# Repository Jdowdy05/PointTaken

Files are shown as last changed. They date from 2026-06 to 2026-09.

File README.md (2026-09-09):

# Point Taken — An Optical Tactile Fingertip

A compact optical tactile fingertip built around the **ams OSRAM TMF8829**. A soft silicone surface deforms under contact; the sensor observes the changing distance to its reflective inner layer. Force and contact information must be obtained through calibration.

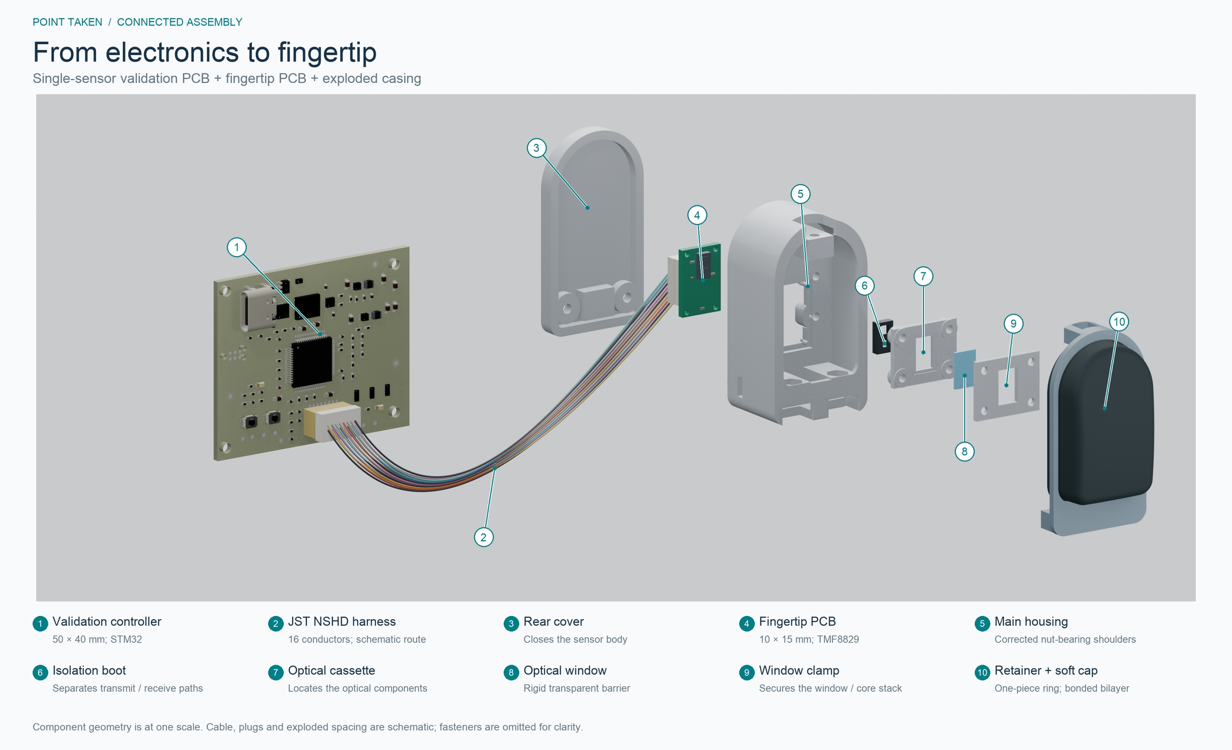
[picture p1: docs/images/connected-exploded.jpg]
Single-sensor validation PCB connected to the fingertip PCB, with the sensor housing and optical components shown in an exploded assembly


*Connected electronics and exploded sensor assembly. Cable routing and exploded spacing are schematic.*

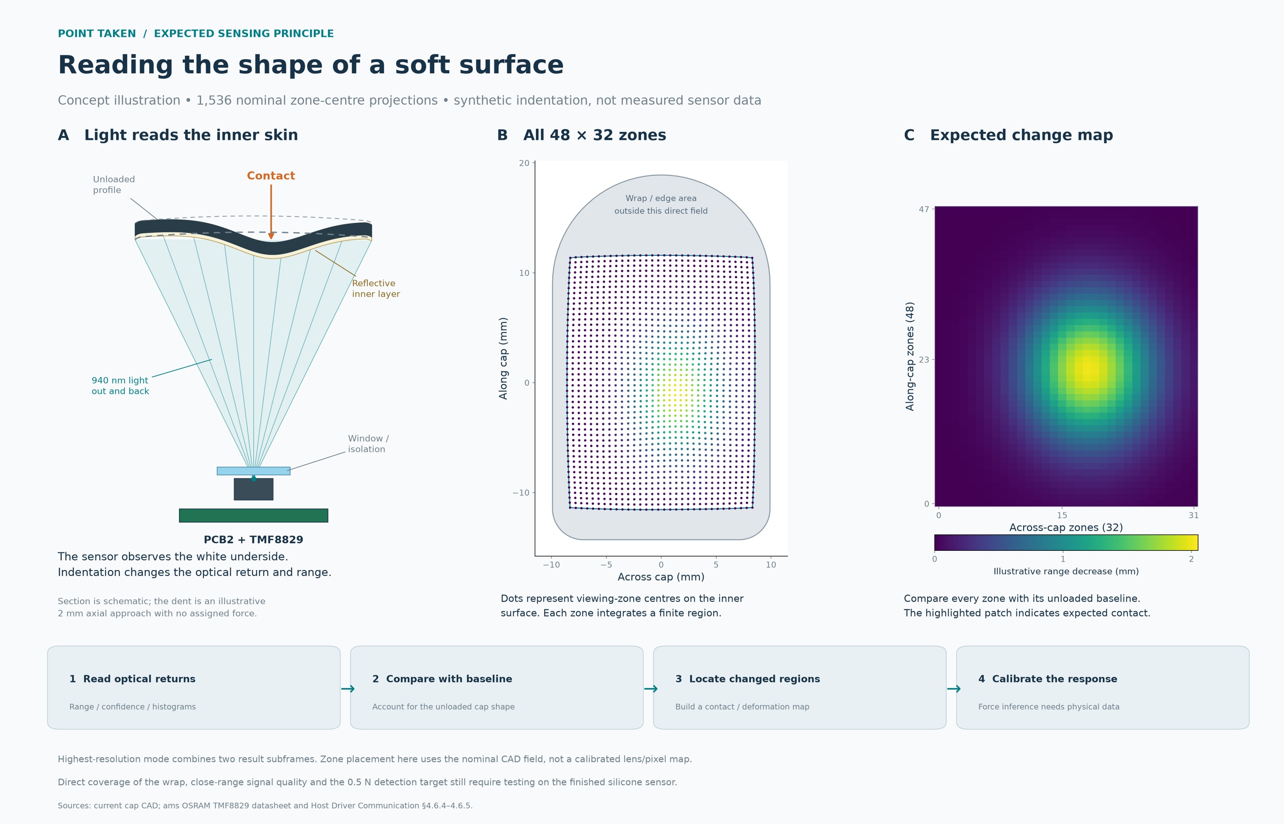
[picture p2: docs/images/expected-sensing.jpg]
Expected optical sensing: representative viewing zones on the reflective inner skin and an illustrative deformation map


*Expected sensing principle. The zone projection and deformation example are illustrative, not calibrated measurements.*

<p align="center">
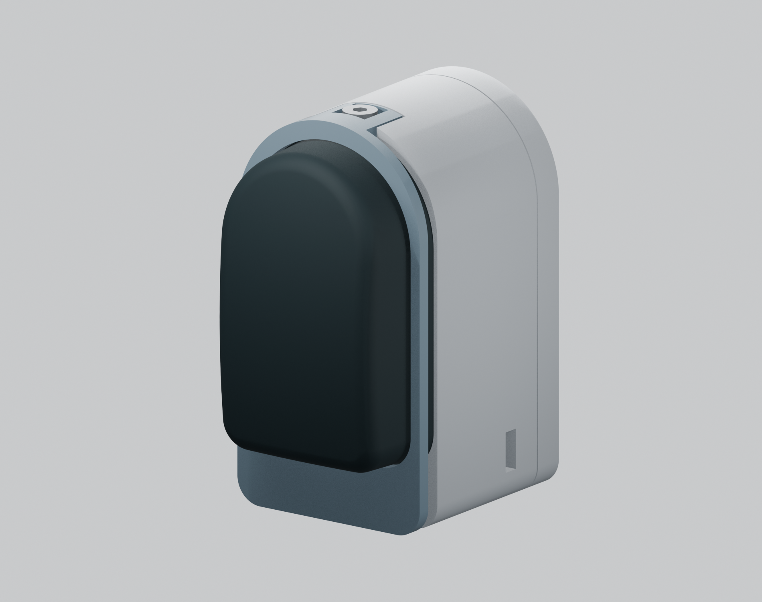
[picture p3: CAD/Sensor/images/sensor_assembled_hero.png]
Assembled Point Taken tactile fingertip
  
</p>

## Repository layout

| Folder | Contents |
| --- | --- |
| [PCBs/](PCBs/) | Native KiCad projects for the five-sensor controller, single-sensor validation rig and fingertip board, plus shared symbols, footprints and 3D reference models. |
| [CAD/Sensor/](CAD/Sensor/) | Corrected sensor housing, one-piece cap retainer, optical parts, compliant-surface geometry, assembled STEP and printable rigid-part STLs. |
| [docs/](docs/) | Material notes, assembly instructions, harness pinout and manufacturer references. |

## Design specifications

| Property | Current design |
| --- | --- |
| Sensing IC | TMF8829 direct time-of-flight sensor; up to **48 ×32 zones** and **940 nm** near-infrared illumination. |
| Sensor enclosure | **24.2 mm wide ×44.5 mm high ×33.8 mm deep**, including the rear locating posts. |
| Fingertip PCB | **10 ×15 mm**, four copper layers, one TMF8829 and four 1.20 mm mounting holes. |
| Main controller | **50 ×50 mm**, six layers, STM32H573ZIT6 and up to five sensor ports; placement complete, **unrouted**. |
| Validation controller | **50 ×40 mm**, six layers, STM32H562RIT6 and one sensor port; routed prototype. |
| Sensor connection | 16-conductor JST NSHD wire harness; SPI primary, optional I3C/I2C lines. |
| Supply architecture | Protected 5 V USB-C controller input; 3.3 V and 1.8 V sensor rails, with an explicit I/O supply. |
| Compliant skin | Nominal **0.90 mm black outer layer +0.30 mm white inner layer**, 1.20 mm total. |
| Target-motion allowance | **6 mm** optical travel allocation; not a measured deformation or force rating. |
| Front retention | **One-piece ring**, three M2 ×6 screws, mechanically captured silicone flange/bead. |
| Rear retention | Two **M2 ×8 screws** for the standalone sensor; side-loaded M2 nuts bear on 4 mm housing shoulders. |

IC capabilities are from the [TMF8829 manufacturer information](https://ams-osram.com/products/sensor-solutions/direct-time-of-flight-sensors-dtof/ams-tmf8829-48x32-multi-zone-time-of-flight-sensor). They do not establish this prototype's effective tactile resolution, frame rate or calibrated force accuracy.

## What the deformable surface should be made from

The current prototype material candidate is **Smooth-On Ecoflex 00-30 platinum-cure silicone**, cast as a bonded two-layer membrane:

- **Outside:** approximately 0.90 mm of black-pigmented silicone to provide the contact surface and block ambient light.
- **Inside:** approximately 0.30 mm of white, titanium-dioxide-filled silicone to provide a diffuse reflective target at 940 nm.

The flexible cap is a cast silicone part. The files in `CAD/Sensor/print/` are the rigid parts intended for 3D printing; compliant-surface meshes describe the casting geometry.

[Ecoflex 00-30 manufacturer instructions](https://www.smooth-on.com/products/ecoflex-00-30/) specify a 1A:1B base mix. Follow the current technical bulletin for preparation and curing. **Pigment/TiO₂ loading and the two-layer bonding process are not yet qualified** for this cap. Black appearance alone does not prove infrared opacity, and white appearance does not establish adequate sensor return. See [Materials](docs/Materials.md) before casting.

## Sensitivity and load targets

These are **design targets, not measured specifications**:

- Detect **0.5 N normal contact**, at least five standard deviations above unloaded repeatability noise over the central 80% of the contact surface.
- Stretch goal: **0.10–0.25 N** detection.
- Produce at least **0.25 mm local target displacement at 0.5–1.0 N** centre load.
- Original mechanical goals: **30 N normal load and 75 N brief overload**. These have not been established for the current cap/housing.

The current state is **a CAD-checked hardware prototype awaiting physical qualification**. CAD clearance checks do not prove sensitivity, tear resistance, layer adhesion, fatigue, creep or overload survival. The single-sensor validation rig and fingertip PCB have routing; the five-sensor controller remains on manufacturing hold. No fabrication or assembly approval is implied by this publication.

## Open and build

1. Open a `.kicad_pro` from [PCBs/](PCBs/) using **KiCad 10** with its standard libraries installed. Project-local library paths are portable.
2. Open [sensor_assembly.step](CAD/Sensor/sensor_assembly.step) in FreeCAD or another STEP-compatible CAD tool. All CAD dimensions are millimetres.
3. Use the **five rigid-part STLs** in [CAD/Sensor/print/](CAD/Sensor/print/), and read the [assembly instructions](docs/Assembly.md). The corrected main housing and one-piece retainer are included.
4. Verify printed nut fits, layer construction and the actual electronics before powered testing. Calibrate the finished silicone article before interpreting deformation as force.

The STEP files provide editable solid geometry; native parametric feature history is not included in this publication. Manufacturer reference documents and component models are identified in [References](docs/References.md).

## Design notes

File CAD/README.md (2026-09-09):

# Sensor CAD

[Sensor/](Sensor/) contains the current standalone tactile sensor, including the corrected rear nut shoulders and one-piece front ring.

Use STEP for solid CAD and the selected STL files for rigid-part printing. The assembly includes reference electronics, the two soft layers and nominal hardware. Component/hardware envelopes are not standalone rigid print jobs.

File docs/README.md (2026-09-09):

# Documentation

- [Assembly](Assembly.md): five rigid parts, fasteners, side-loaded rear nuts and one-piece cap ring.
- [Materials](Materials.md): Ecoflex bilayer candidate, optical additives and qualification limits.
- [Harness](Harness.md): 16-wire JST NSHD connector pinout.
- [References](References.md): manufacturer documentation and reference-model provenance.

The root [README](../README.md) lists the hardware dimensions and design targets.

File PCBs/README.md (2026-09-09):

# PCB projects

Open the `.kicad_pro` file in the appropriate folder with KiCad 10 and its standard symbol, footprint and 3D model libraries.

| Project | Nominal board size | Layers | Purpose and state |
| --- | --- | ---: | --- |
| [PCB1_Controller](PCB1_Controller/) | 50 ×50 mm | 6 | Five-sensor STM32H573 controller. Placement present; zero tracks/vias. Unrouted and on manufacturing hold. |
| [PCB1_Single_Sensor_Validation_Rig](PCB1_Single_Sensor_Validation_Rig/) | 50 ×40 mm | 6 | STM32H562 single-sensor bring-up controller. Routed prototype. |
| [PCB2_Fingertip_Sensor](PCB2_Fingertip_Sensor/) | 10 ×15 mm | 4 | TMF8829 fingertip module. Routed prototype. |

`JustTheTip_Connectors.pretty/` and `3dmodels/` are shared by the three projects. Keep the folder relationships intact. Custom symbols and other custom footprints are stored beside their owning projects. Library tables use `${KIPRJMOD}`, `${KICAD10_SYMBOL_DIR}` and `${KICAD10_FOOTPRINT_DIR}`; stock component models use `${KICAD10_3DMODEL_DIR}`.

Schematic and board files retain the electrical design contents. Publication changes library paths and organization, not electrical routing. Four nonexistent PCB1 stock-model references now point to the included exact-part envelope proxies for TCPP01-M12, ESDA25P35-1U1M, TPS259531 and CSD17577Q5A. Native board loading and schematic/board SVG exports were checked; `manifest.json` records file hashes and board statistics. These publication checks are not a fresh ERC/DRC, EMC or manufacturing review.

Each project has `previews/top.svg`, `previews/bottom.svg` and schematic pages in `previews/schematics/`. Bottom previews use the board's unmirrored coordinate convention. Copper plots are for inspection, not fabrication files. Generate fabrication outputs from the selected source revision after reviewing its rules, stackup, DRC/ERC and manufacturing requirements.

The hierarchical filename `Sensor_FFC_Ports.kicad_sch` in PCB1 is historical: its actual connector interface is JST NSHD discrete wire. See the [16-wire interface](../docs/Harness.md).

The custom 3D models named `*_proxy.step` are envelope approximations for packaging; manufacturer drawings govern exact component and mating dimensions.

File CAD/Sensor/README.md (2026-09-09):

# Standalone fingertip sensor

Envelope: **24.2 ×44.5 ×33.8 mm** (width ×height ×depth, including rear locating posts).

| Path | Use |
| --- | --- |
| `sensor_assembly.step` | Complete 54-solid sensor assembly, including PCB and hardware references. |
| `parts/` | Five rigid-part STEP files. |
| `print/` | Matching STL files for the main housing, back housing, one-piece retainer, optical cassette and window clamp. |
| `compliant_surface/` | Black outer cap and white inner target STEP/STL geometry for silicone casting. |
| `reference/` | PCB, optical boot and window reference solids/meshes. |
| `images/` | Actual CAD renders, including six assembled views and an exploded assembly. |
| `manifest.json` | Dimensions, file hashes, export checks and standalone rear-fastener contact checks. |

The cap and retainer remove together after the three M2 ×6 front screws are removed. Separating the silicone from the one-piece ring requires flexing the flange and must be tried on a sacrificial cap. The corrected rear nuts load from the sides and bear on main-housing shoulders; the standalone rear screws are M2 ×8.

Coordinates are X across the sensor, Y toward the arched tip and Z toward the contact surface. All dimensions are millimetres. Orient parts deliberately in the slicer. Candidate rigid material is FDM PETG; printer tolerances, nut fit and allowable tightening torque need physical verification.

These are editable STEP solids and STL exports. The CAD construction feature history is not included. [Assembly](../../docs/Assembly.md) and [material guidance](../../docs/Materials.md) apply to this revision.

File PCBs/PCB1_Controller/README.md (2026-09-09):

# PCB1 Controller

Open [PCB1_Controller.kicad_pro](PCB1_Controller.kicad_pro) in KiCad 10.

Five-sensor controller; placement only, zero tracks/vias. Manufacturing hold.

- [Top copper/silkscreen preview](previews/top.svg)
- [Bottom copper/silkscreen preview](previews/bottom.svg)
- [Schematic pages](previews/schematics/)

Keep the shared connector and 3D-model folders alongside the board project. See the [PCB index](../README.md) for library setup and status.

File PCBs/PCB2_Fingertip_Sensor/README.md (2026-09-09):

# PCB2 Fingertip Sensor

Open [PCB2_Fingertip_Sensor.kicad_pro](PCB2_Fingertip_Sensor.kicad_pro) in KiCad 10.

Routed prototype. Native source is included; physical bring-up and manufacturing review remain necessary.

- [Top copper/silkscreen preview](previews/top.svg)
- [Bottom copper/silkscreen preview](previews/bottom.svg)
- [Schematic pages](previews/schematics/)

Keep the shared connector and 3D-model folders alongside the board project. See the [PCB index](../README.md) for library setup and status.

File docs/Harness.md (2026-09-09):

# Sensor harness

The connector is a 16-circuit, 1.0 mm pitch JST NSHD wire harness: BM16B-NSHDZS-TFT board headers, NSHDR-16V-Z housings and SNSHD-003T-P0.2 contacts.

| Pin | Signal | Notes |
| --- | --- | --- |
| 1 | GND | Ground return. |
| 2 | 3V3_TOF | Sensor 3.3 V rail. |
| 3 | TOF_VIO | TMF8829 I/O rail; strapped to 3.3 V on PCB1 by default. |
| 4 | GND | Power return. |
| 5 | 1V8_TOF | Sensor VDDD rail. |
| 6 | GND | Power return. |
| 7 | SPI_SCLKx | Per-port SCLK preferred. |
| 8 | SPI_MOSIx | Per-port MOSI preferred. |
| 9 | SPI_MISOx | Per-port MISO preferred. |
| 10 | SPI_CSn | Per-port chip select. |
| 11 | I3C_SCLx / AUX1 | Optional bring-up/debug I3C/I2C; pull up to TOF_VIO. |
| 12 | I3C_SDAx / AUX2 | Optional bring-up/debug I3C/I2C; pull up to TOF_VIO. |
| 13 | ENx | Per-port sensor enable. |
| 14 | INTx | Per-port interrupt. |
| 15 | DET_IDx | Presence/revision detection. |
| 16 | GND | Fourth ground return at the cable edge. |

Pin numbers and signal roles match the native PCB2 connector. Net names vary by controller; pin 3 is the explicit I/O supply and pin 16 is ground. Define housing orientation and pin-1-to-pin-1 continuity in the physical harness drawing before assembly. The older FFC/FPC interface is retired.

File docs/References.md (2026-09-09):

# References and component geometry

- [ams OSRAM TMF8829 product and datasheets](https://ams-osram.com/products/sensor-solutions/direct-time-of-flight-sensors-dtof/ams-tmf8829-48x32-multi-zone-time-of-flight-sensor): sensor capabilities, electrical interface and optical guidance. Existing reference PDFs and optical models are retained under `references/`.
- [Smooth-On Ecoflex 00-30](https://www.smooth-on.com/products/ecoflex-00-30/): current prototype silicone candidate and preparation/cure instructions.
- [Smooth-On Dragon Skin 10 NV technical bulletin](https://www.smooth-on.com/tb/files/DRAGON_SKIN_10_NV_TB.pdf): earlier outer-layer material candidate.
- [Stretchable silicone reflective coating study](https://doi.org/10.1039/D2SM00869F): supporting material research; its formulation does not qualify the current sensor.
- [JST NSHD series](https://www.jst-mfg.com/product/pdf/eng/eNSHD.pdf): board header, cable housing, contacts and recommended footprint.
- [KiCad libraries](https://www.kicad.org/libraries/): standard symbols, footprints and 3D models used by the PCB projects.

Files named `*_proxy.step` are project component-envelope approximations. The PCB/CAD assembly also includes optical reference geometry; use manufacturer drawings for exact dimensions, optical tolerances and mating requirements. No model color establishes a material's infrared properties.

Manufacturer documents and reference geometry retain their original ownership and terms. KiCad-derived library content remains subject to its upstream terms. This repository does not declare a blanket license over third-party reference material, and no new project-wide license is assigned by this update.

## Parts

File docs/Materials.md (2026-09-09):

# Compliant surface material

## Current prototype candidate

Use **Ecoflex 00-30 platinum-cure silicone** as the starting base material for the current cap study. It is a candidate formulation, not a demonstrated route to the required force sensitivity. The [manufacturer product page and technical bulletin](https://www.smooth-on.com/products/ecoflex-00-30/) govern its 1A:1B mixing and curing instructions.

| Layer | Nominal normal thickness | Purpose |
| --- | ---: | --- |
| Black outer silicone | 0.90 mm | Contact skin and ambient-light suppression. |
| White TiO₂-filled inner silicone | 0.30 mm | Flexible diffuse reflective target facing the 940 nm sensor. |
| Total skin | 1.20 mm | Bonded bilayer; the inner target deforms with the outside. |

Use silicone-compatible black pigment and a dispersed white titanium-dioxide additive suitable for the selected silicone process. There is no approved additive mass fraction for this final geometry. Additives can change cure, stiffness and optical response, so do not infer performance from color or unfilled-silicone hardness alone.

The intended process is a two-stage cast with reliable interlayer bonding. Preserve the designed flange and bead: the ring mechanically captures those features. The geometry files do not constitute a qualified mold, gate/vent layout or casting process.

## Earlier material study

The original material study proposed Dragon Skin 10 NV outside and Ecoflex 00-10 with micrometric rutile TiO₂ inside. A 1.0 vol% TiO₂ coating was a research starting point, not a validated recipe for Ecoflex 00-30 or this cap. The current cap source identifies Ecoflex 00-30 as a later candidate; physical testing has not resolved the formulation choice. These alternatives should not be treated as interchangeable qualified materials.

## Qualification required

- Cure compatibility, consistent wall thickness and two-layer adhesion.
- Infrared opacity of the black skin at its actual thickness; original target was optical density ≥3 at 940 nm (≤0.1% direct transmission).
- Adequate diffuse return from the inner target without saturation or large baseline drift; original target was 70–90% diffuse/hemispherical return at 940 nm.
- Required 0.5 N contact detection and low-force target displacement after calibration of the actual article.
- Flange insertion/removal without tearing, skin abrasion, creep, fatigue and overload behavior.

The one-piece ring requires the silicone flange to flex during cap replacement. That service operation is not a proven strain or life result.

The compliant-surface STLs are casting references. FDM printing a TPU version changes the mechanics and would require a separate sensitivity evaluation. FDM-printed tooling, if developed, would need surface finishing, dimensional checks and a silicone cure-compatibility trial.

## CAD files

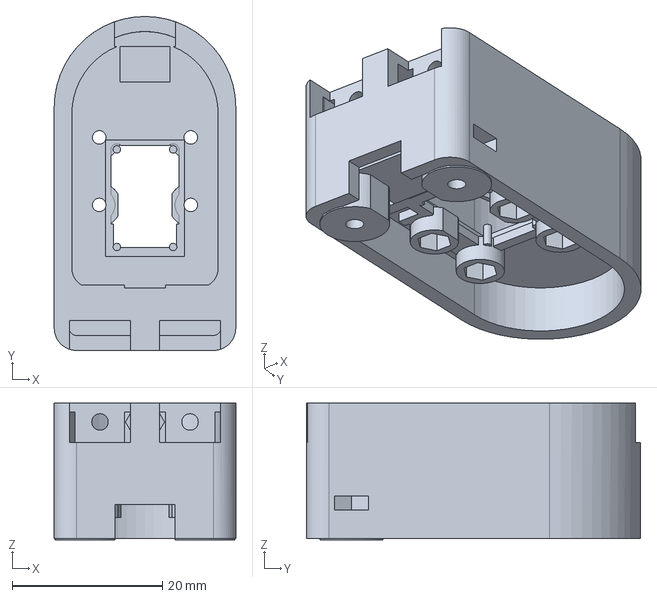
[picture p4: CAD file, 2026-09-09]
CAD/Sensor/parts/main_housing.step
24.2 x 44.5 x 18.2 mm

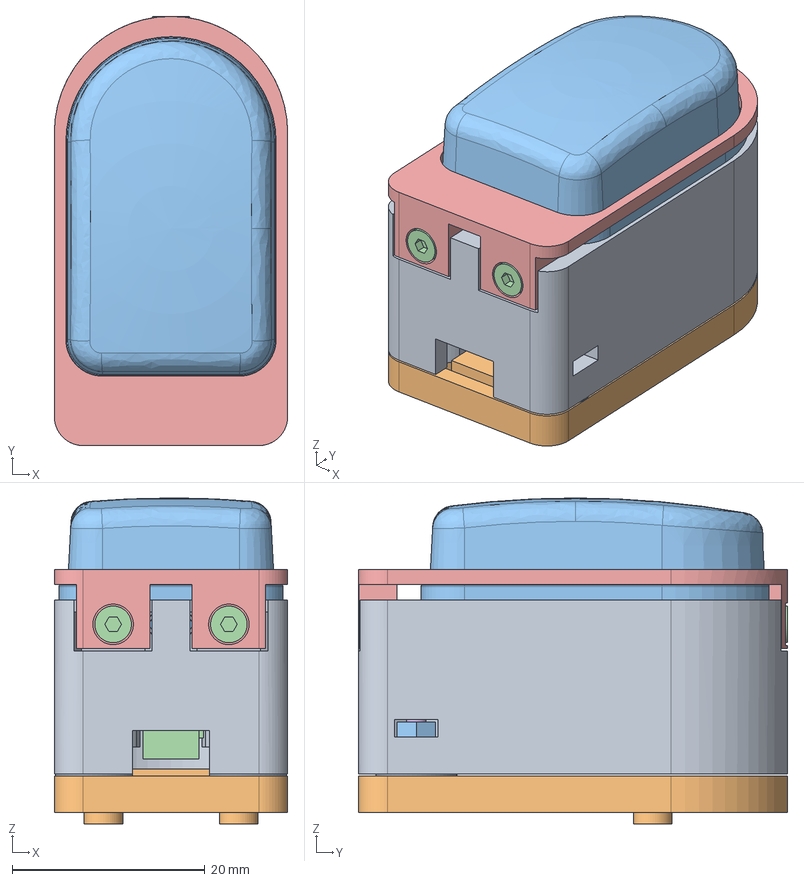
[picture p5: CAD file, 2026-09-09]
CAD/Sensor/sensor_assembly.step
24.2 x 44.5 x 33.8 mm

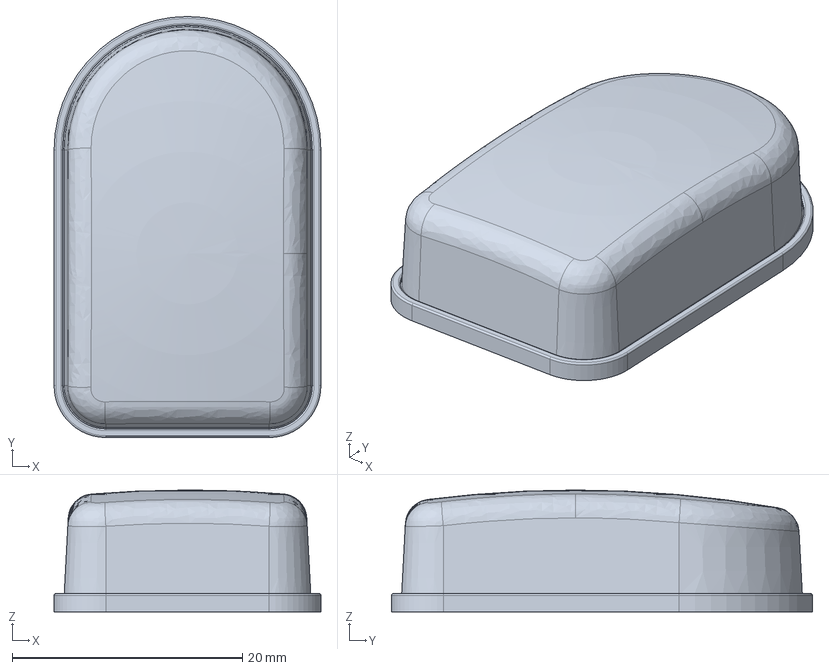
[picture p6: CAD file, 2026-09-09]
CAD/Sensor/compliant_surface/black_wrap_cap.step
23.2 x 36.6 x 10.6 mm

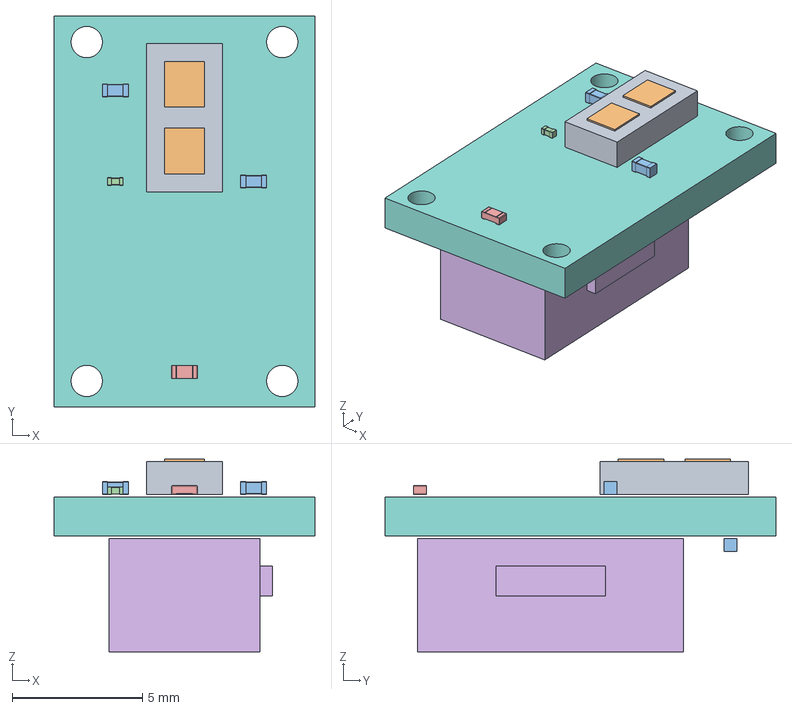
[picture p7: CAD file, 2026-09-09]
CAD/Sensor/reference/PCB2_reference.step
10.0 x 15.0 x 7.39 mm

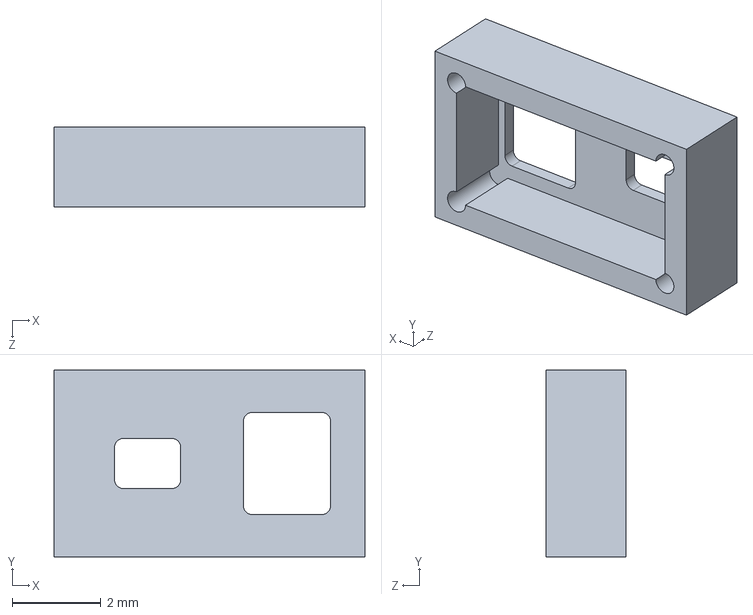
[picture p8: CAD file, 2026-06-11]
docs/references/TMF8829_Optical_Design_Guide/TMF8829_Rubber_Boot_0mm3.STEP
7.00 x 4.20 x 1.80 mm

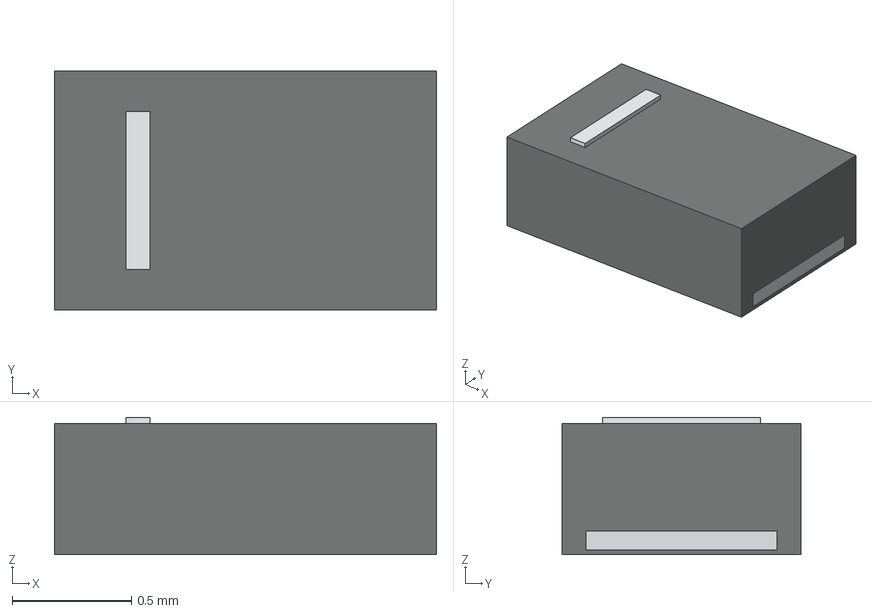
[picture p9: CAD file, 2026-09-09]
PCBs/3dmodels/ST_ESDA25P35_1U1M_QFN2_1p6x1p0_proxy.step
1.60 x 1.00 x 0.575 mm
molded_body
terminal_1
terminal_2
polarity_bar

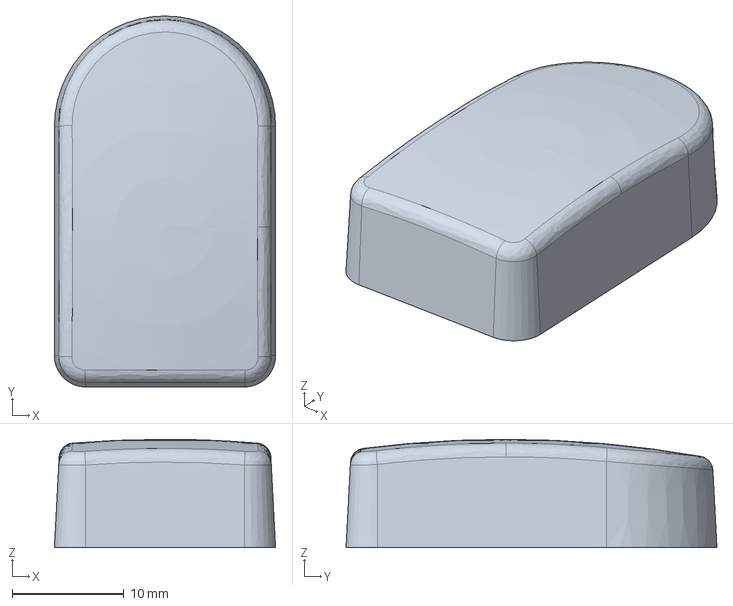
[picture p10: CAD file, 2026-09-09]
CAD/Sensor/compliant_surface/white_inner_target.step
19.8 x 33.2 x 9.70 mm

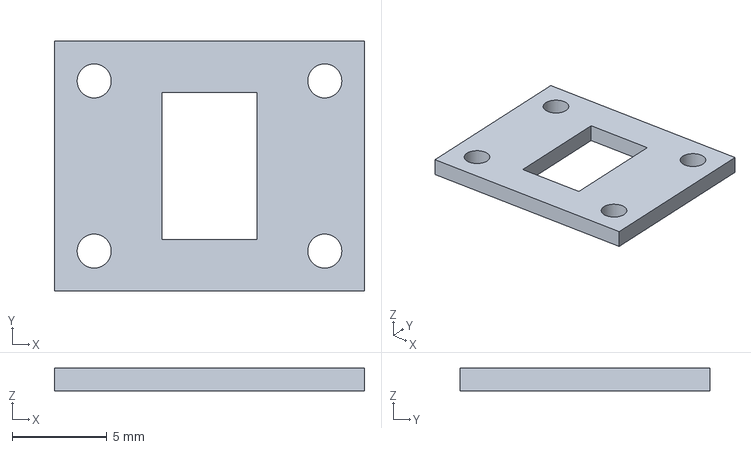
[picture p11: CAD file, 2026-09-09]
CAD/Sensor/parts/window_clamp.step
16.4 x 13.2 x 1.20 mm

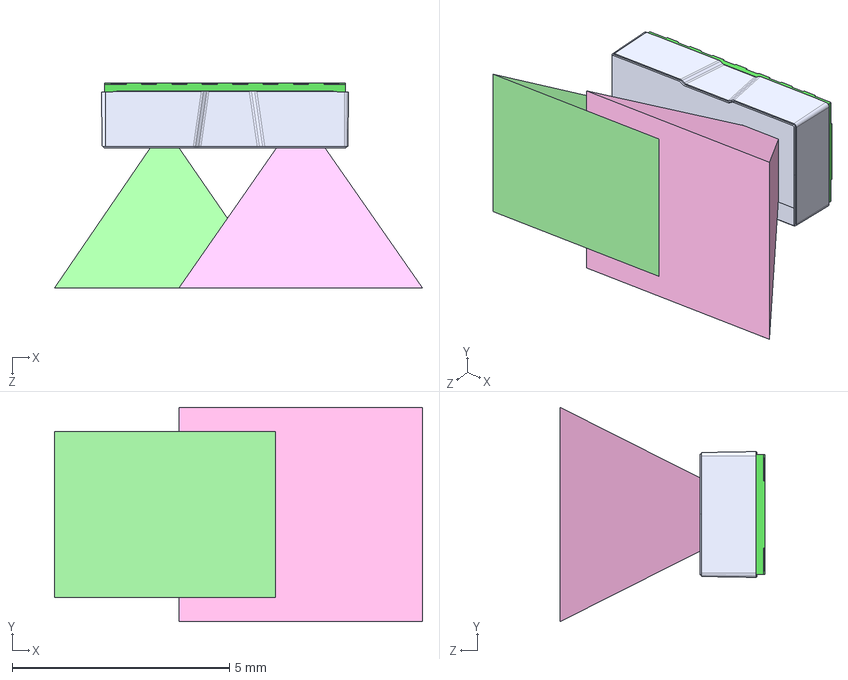
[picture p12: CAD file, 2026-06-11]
docs/references/TMF8829_Optical_Design_Guide/TMF8829_with_FOI_FOV.STEP
8.48 x 4.94 x 4.72 mm
Substrate_
Receiver_
CUT LID_
Lens1_withFOI
Lens2_
Emitter_WithConeFOI_ x 2
Lens2_with2FOI_combined_
LID_

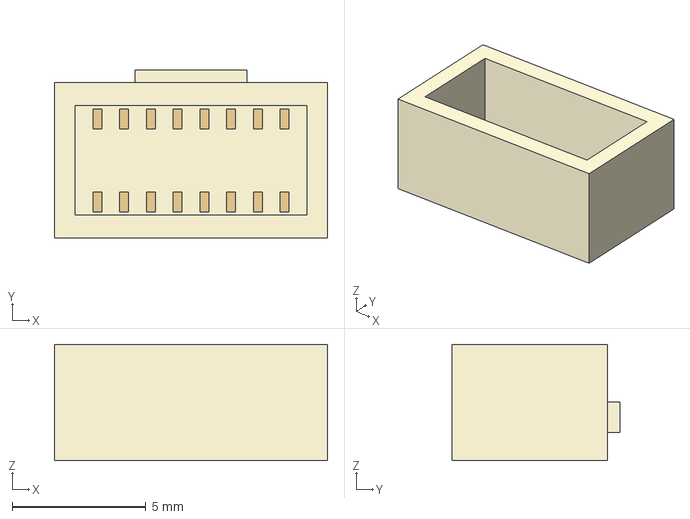
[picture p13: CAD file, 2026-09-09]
PCBs/3dmodels/JST_BM16B_NSHDZS_TFT_envelope_proxy.step
10.2 x 6.28 x 4.35 mm
ivory_shell
contacts

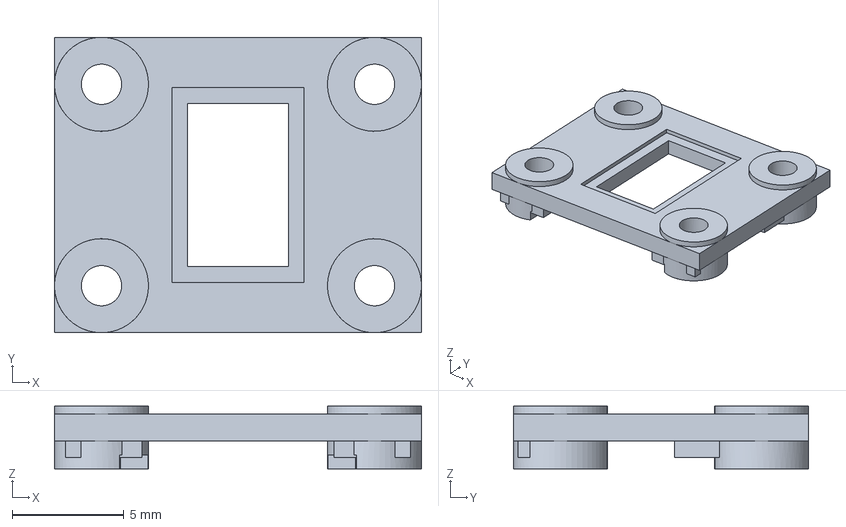
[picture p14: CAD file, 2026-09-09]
CAD/Sensor/parts/P3_optical_cassette.step
16.4 x 13.2 x 2.80 mm

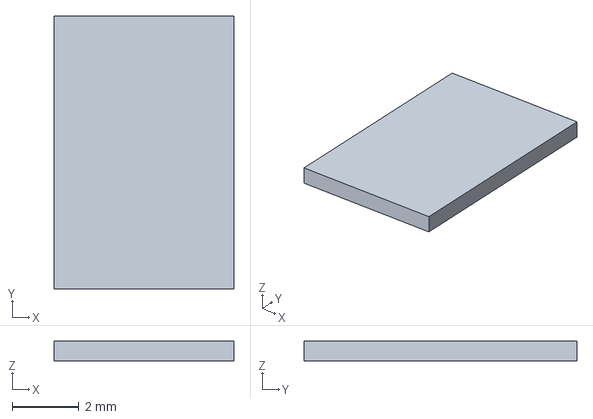
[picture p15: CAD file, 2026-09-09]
CAD/Sensor/reference/window_reference.step
5.40 x 8.20 x 0.6 mm

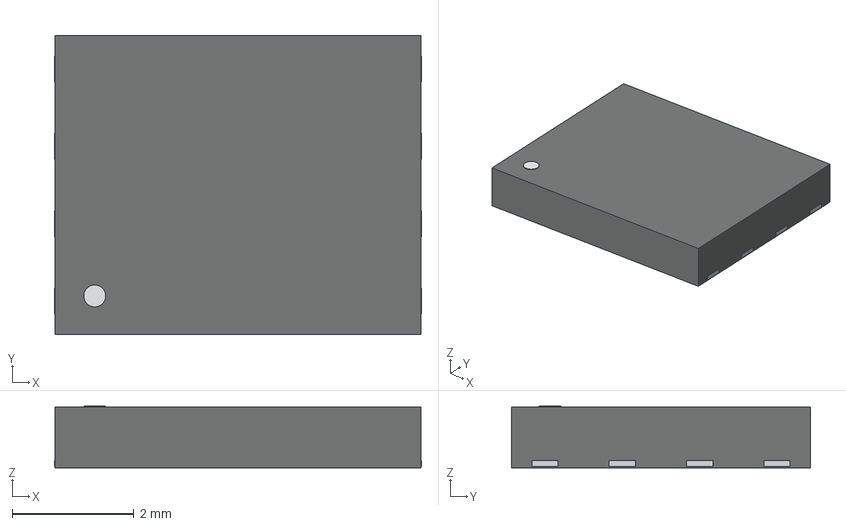
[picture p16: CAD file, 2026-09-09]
PCBs/3dmodels/TI_CSD17577Q5A_DQJ_6p0x4p9_proxy.step
6.02 x 4.90 x 1.01 mm
molded_body
terminal_flanks
pin_1_marker

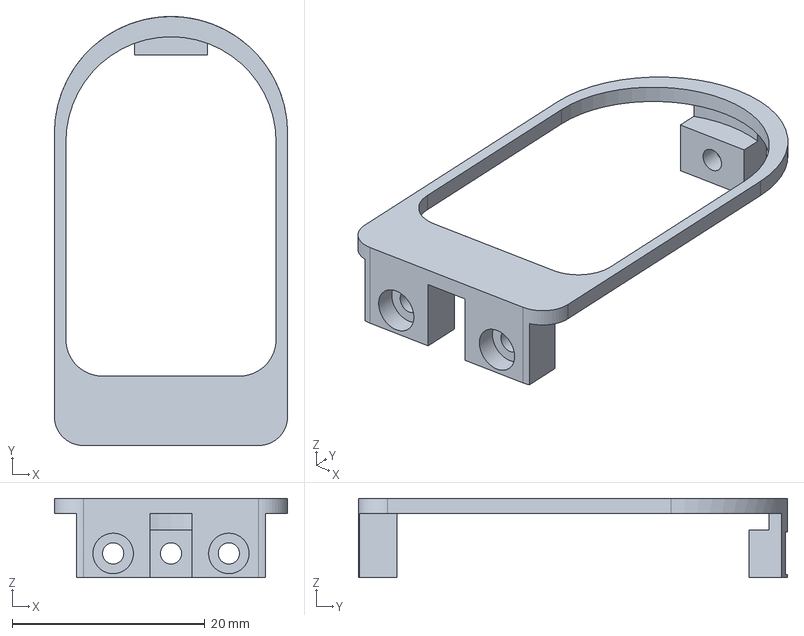
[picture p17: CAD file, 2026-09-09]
CAD/Sensor/parts/cap_retainer_one_piece.step
24.2 x 44.5 x 8.20 mm

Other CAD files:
CAD/Sensor/reference/boot_reference.step
PCBs/3dmodels/ST_TCPP01_M12_QFN12_3p0x3p0_proxy.step
CAD/Sensor/parts/back_housing.step
PCBs/3dmodels/TDK_TFM201610ALM_R47MTAA_2p0x1p6_proxy.step
CAD/Sensor/compliant_surface/black_wrap_cap.stl
CAD/Sensor/compliant_surface/white_inner_target.stl
CAD/Sensor/print/P3_optical_cassette.stl
CAD/Sensor/print/back_housing.stl
CAD/Sensor/print/cap_retainer_one_piece.stl
CAD/Sensor/print/main_housing.stl
CAD/Sensor/print/window_clamp.stl
CAD/Sensor/reference/PCB2_reference.stl
CAD/Sensor/reference/boot_reference.stl
CAD/Sensor/reference/window_reference.stl
PCBs/3dmodels/TI_DMQ0006A_VSON_HR_6_1p5x1p5_proxy.step
PCBs/3dmodels/TI_TPS259531_DSG0008A_2p0x2p0_proxy.step
PCBs/3dmodels/TMF8829_package_envelope_proxy.step

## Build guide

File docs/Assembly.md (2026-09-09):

# Sensor assembly

## Rigid parts and hardware

Print one each of the five parts in `CAD/Sensor/print/`: main housing, back housing, one-piece cap retainer, optical cassette and window clamp. The silicone cap/inner target, PCB, optical boot, window and metal fasteners are not rigid print jobs.

| Fastener | Quantity | Purpose |
| --- | ---: | --- |
| M1.6 ×8 socket-head screw | 4 | Optical core retention |
| M1.6 hex nut | 4 | Optical core retention |
| M2 ×6 socket-head screw | 3 | Front cap-retainer ring |
| M2 hex nut | 3 | Front retainer seats |
| M2 ×8 socket-head screw | 2 | Standalone back housing |
| M2 hex nut | 2 | Corrected side-loading rear seats |

Screw lengths are measured under the head. The modeled M2 nuts are 4.0 mm across flats and 1.6 mm thick. Check the actual hardware and printed pockets before assembly; there is no qualified tightening torque.

## Sequence

1. Inspect and finish the print surfaces and holes. Check each nut pocket and screw bore off the assembly. Ensure the rear nuts seat and resist spinning.
2. Assemble the PCB, cassette, optical boot and window/clamp with their four M1.6 fasteners. Keep the optical window clean, the transmit/receive isolation intact and the harness clear of hardware.
3. Fit the front retainer nuts into the housing before closing the front. Gently flex the cast cap's flange into the one-piece ring off the housing, checking the skins and flange for damage. This operation needs a physical trial on a sacrificial cap.
4. Seat the cap/ring cartridge on the housing and install the three M2 ×6 screws: one at the arched tip and two at the heel. The screws bear on rigid mounting faces; they do not pierce the silicone.
5. Insert the two rear M2 nuts through the outer left/right slots near the body's flat heel. These slots leave **4 mm housing shoulders between the nuts and the backplate**. Hold the nuts in their seats until engaged by the screws.
6. Seat the back housing and install the two **M2 ×8** rear screws. Tighten evenly. The load path is screw head → back housing → main-housing shoulder → nut.
7. Check cable strain relief and printed fit before powering the PCB. The existing strain-relief allocation is 4 mm; a thinner harness needs appropriate packing or a separately checked restraint. Calibrate the cast cap before interpreting deformation as force.

For front service, remove all three front screws and withdraw the **ring and soft cap together** from the sensing face. Their combined extraction path clears the rigid assembly in CAD. Do not force the ring alone past the undeformed flange. To replace only the silicone, detach the cartridge first, then gently fold/peel its flange out of the ring.

The current prototype has geometric fit and retention checks. Material strength, printed tolerances, flange tear resistance, repeated service, optical sensitivity and overload survival remain unqualified.

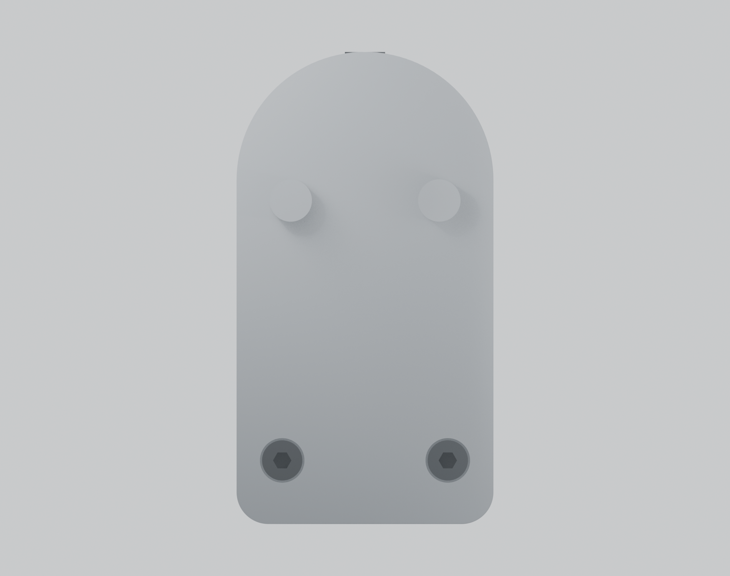
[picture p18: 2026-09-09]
CAD/Sensor/images/sensor_assembled_back.png

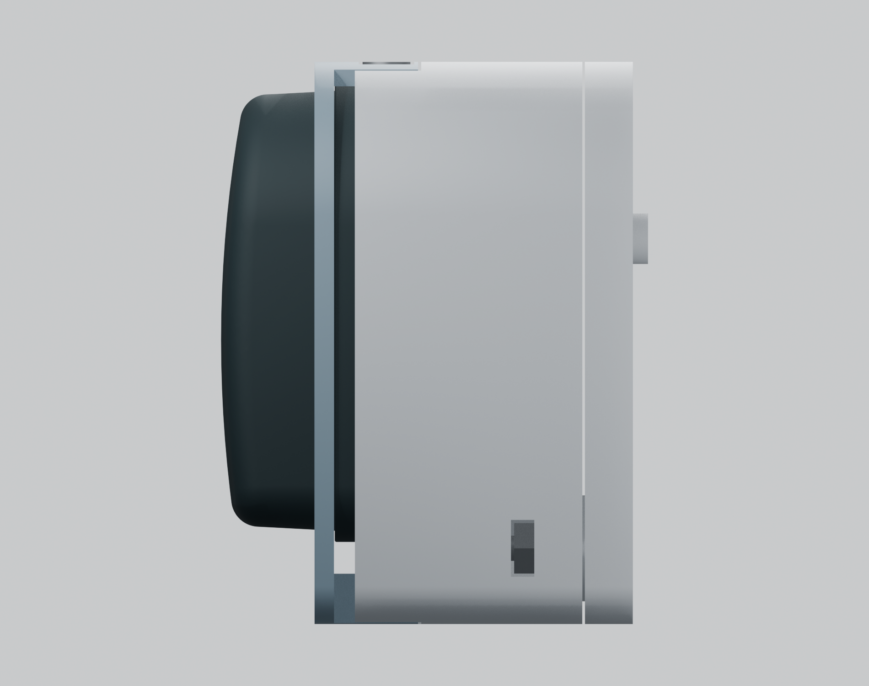
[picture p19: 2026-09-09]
CAD/Sensor/images/sensor_assembled_side.png

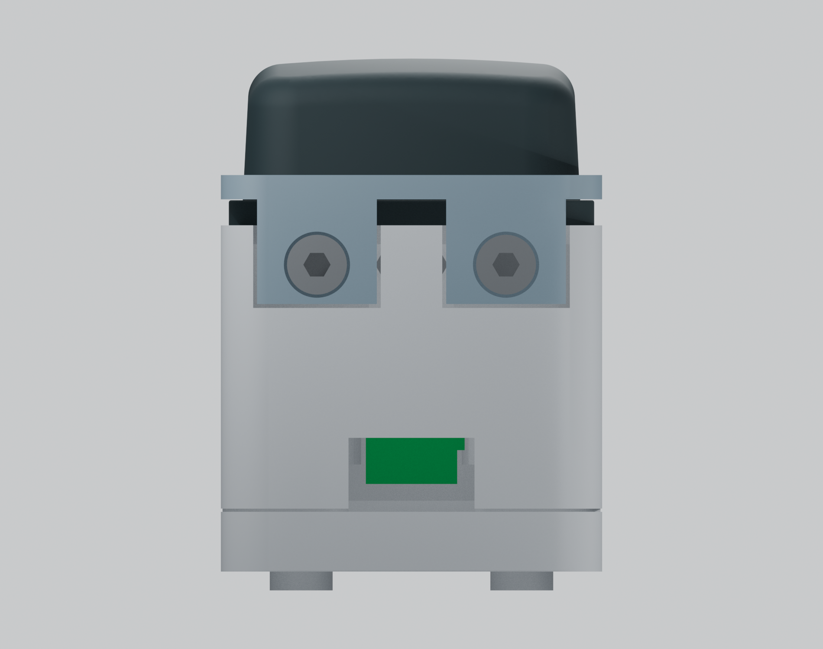
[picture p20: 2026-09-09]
CAD/Sensor/images/sensor_assembled_base.png

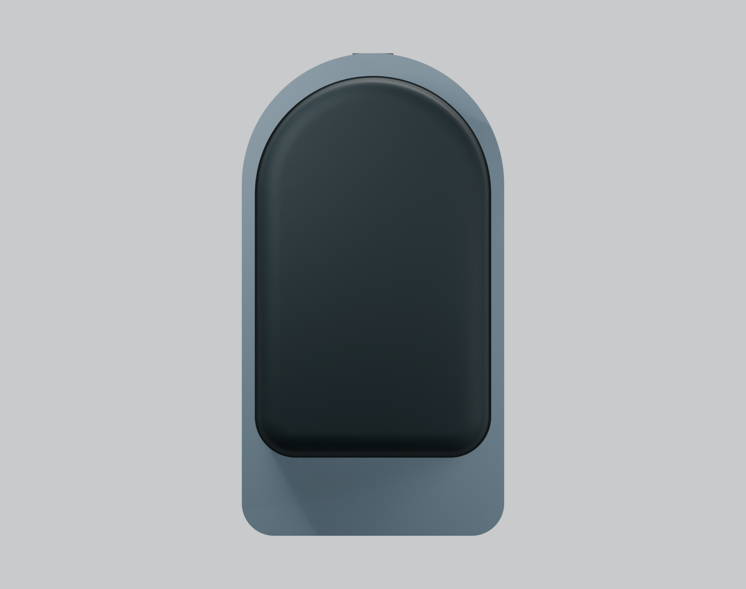
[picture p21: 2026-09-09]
CAD/Sensor/images/sensor_assembled_front.png

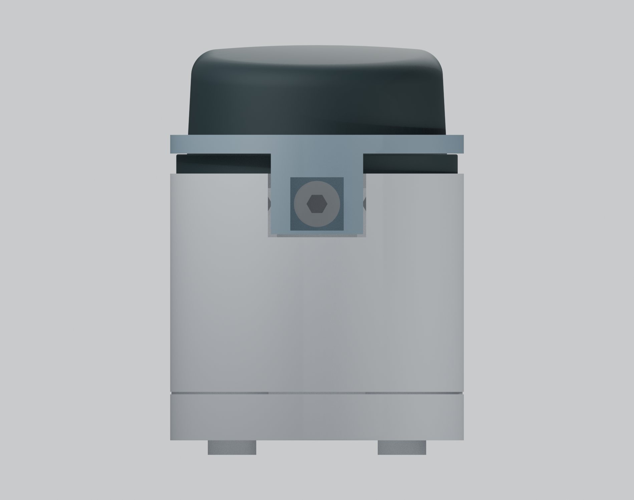
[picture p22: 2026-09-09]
CAD/Sensor/images/sensor_assembled_tip.png

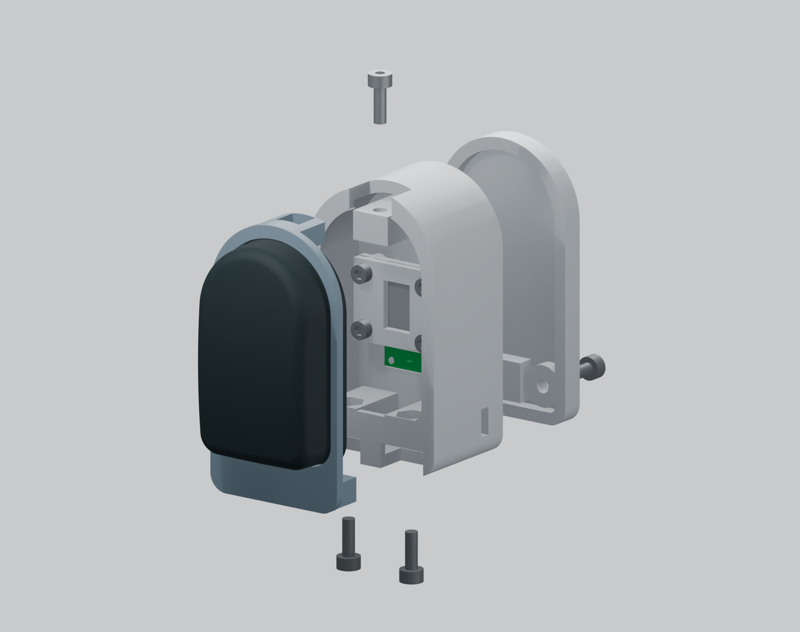
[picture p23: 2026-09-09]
CAD/Sensor/images/sensor_assembly_exploded.png

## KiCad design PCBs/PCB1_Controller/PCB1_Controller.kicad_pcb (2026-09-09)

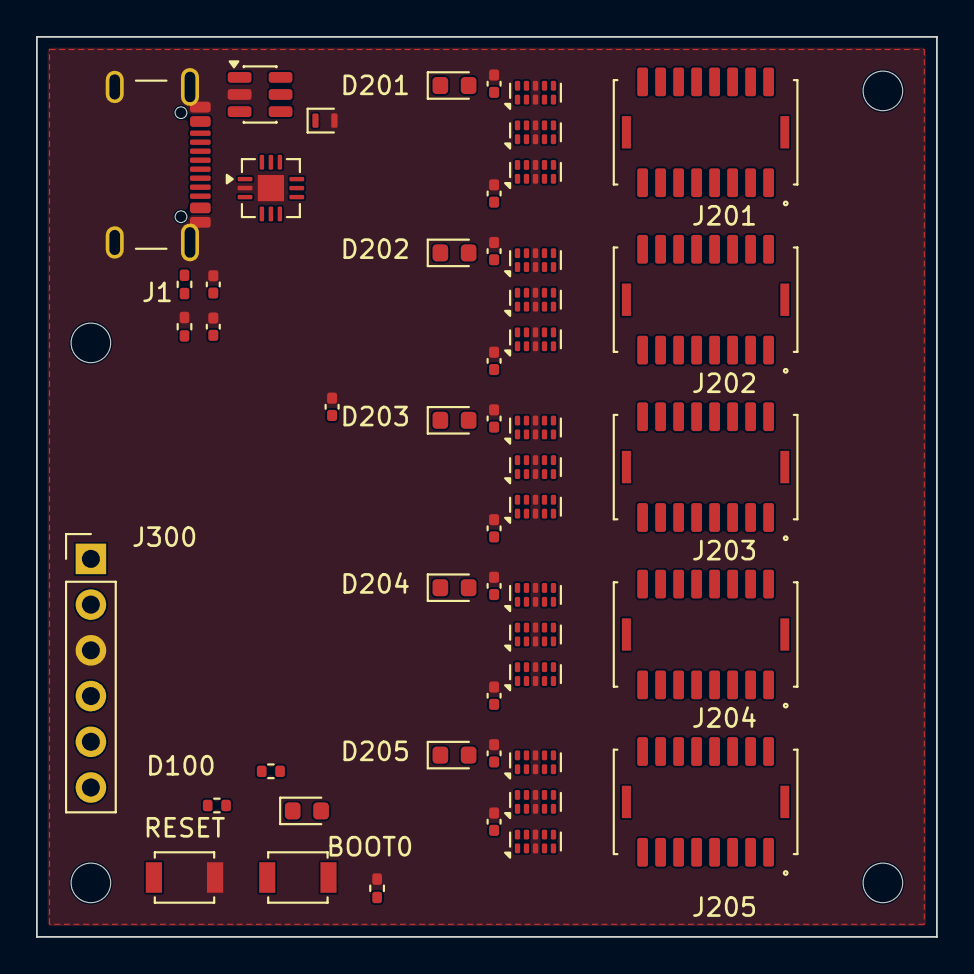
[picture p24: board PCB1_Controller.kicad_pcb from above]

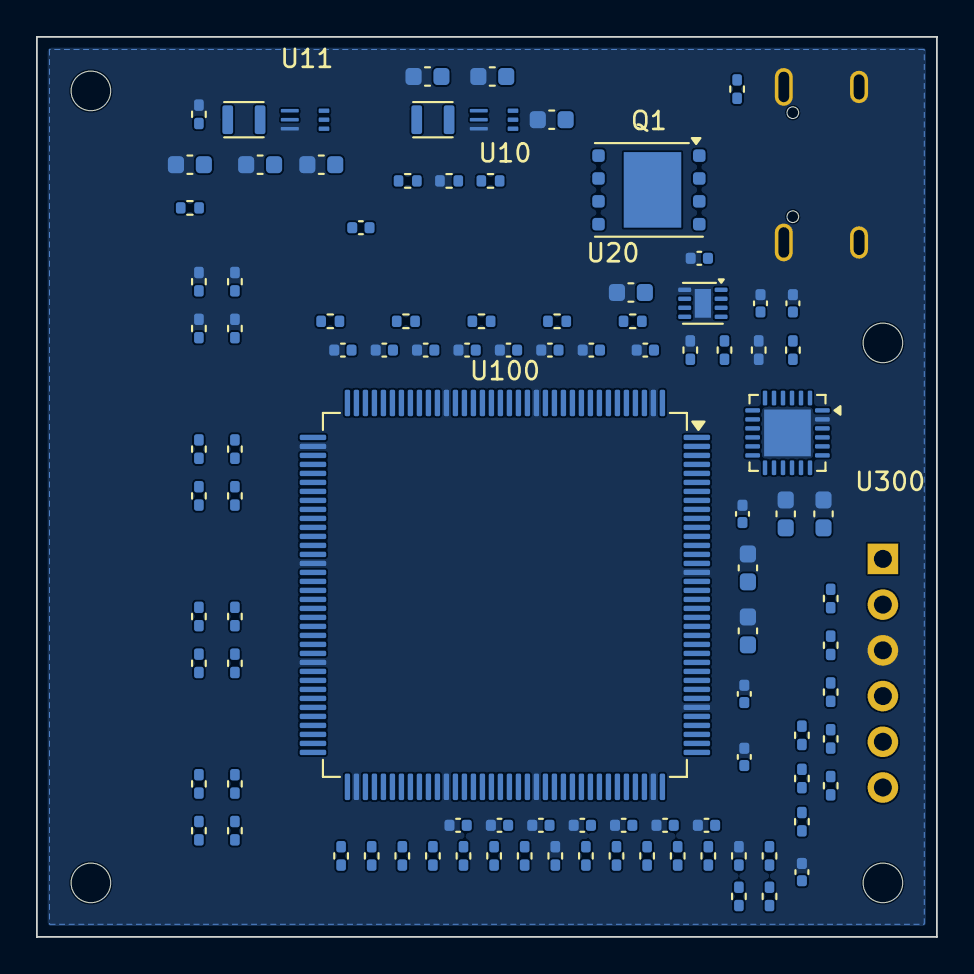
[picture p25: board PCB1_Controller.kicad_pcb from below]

Board: 6 copper layers, 50.0 x 50.0 mm, 153 parts (98 on the bottom side), 103 nets, no tracks yet.

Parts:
C1, C2: 330pF; C_0402_1005Metric
C3: 100nF 50V; C_0402_1005Metric
C4: 2.2uF 50V; C_0603_1608Metric
C5, C201, C202, C203, C204, C205, C211, C212, C213, C214, C215, C260, C303: 1uF; C_0402_1005Metric
C6: 3.3nF 50V; C_0402_1005Metric
C10, C20, C330, C340: 4.7uF; C_0603_1608Metric
C11, C12, C21, C22: 10uF; C_0603_1608Metric
C13: 120pF; C_0402_1005Metric
C300, C304, C310, C311, C312, C313, C314, C315, C316, C317, C318, C319, C320, C321, C322, C323, C341, C342: 100nF; C_0402_1005Metric
C301, C302: 2.2uF; C_0603_1608Metric
D1: ESDA25P35-1U1M; ST_QFN-2L_1.6x1.0mm
D100: MCU_STATUS green; LED_0603_1608Metric
D201: TOF1_DATA green; LED_0603_1608Metric
D202: TOF2_DATA green; LED_0603_1608Metric
D203: TOF3_DATA green; LED_0603_1608Metric
D204: TOF4_DATA green; LED_0603_1608Metric
D205: TOF5_DATA green; LED_0603_1608Metric
J1: USB4105-GF-A-120; USB_C_Receptacle_GCT_USB4105-xx-A_16P_TopMnt_Horizontal
J201, J202, J203, J204, J205: BM16B-NSHDZS-TFT; JST_BM16B-NSHDZS-TFT_2x08_P1.00mm_Vertical
J300: TSW-106-07-G-S SWD; PinHeader_1x06_P2.54mm_Vertical
L10, L11: 0.47uH; TDK_TFM201610ALM-R47MTAA_2.0x1.6mm
MH1, MH2, MH3, MH4: M2 2.2mm NPTH; MountingHole_2.2mm_M2
Q1: CSD17577Q5A; TI_CSD17577Q5A_DQJ_VSONP-8_4.9x6.0mm
R1: 80.6k; R_0402_1005Metric
R2: 24k; R_0402_1005Metric
R3, R5, R211, R212, R213, R214, R215, R300, R301: 10k; R_0402_1005Metric
R4, R262, R302, R303, R309: 0R; R_0402_1005Metric
R6: 681R; R_0402_1005Metric
R10: 450k; R_0402_1005Metric
R11, R12, R20, R201, R202, R203, R204, R205, R221, R222, R223, R224, R225, R231, R232, R233, R234, R235, R311, R312: 100k; R_0402_1005Metric
R241, R242, R243, R244, R245, R246, R247, R248, R249, R250: 22R; R_0402_1005Metric
R260, R261: 2.2k; R_0402_1005Metric
R271, R272, R273, R274, R275, R310: 1k; R_0402_1005Metric
R304, R305: 0R DNP; R_0402_1005Metric
R306: 22.1k DNP; R_0402_1005Metric
R307: 47.5k DNP; R_0402_1005Metric
R308: 1k DNP; R_0402_1005Metric
SW100: RESET B3U-1000P; SW_SPST_B3U-1000P
SW101: BOOT0 B3U-1000P; SW_SPST_B3U-1000P
U1: TCPP01-M12; QFN-12-1EP_3x3mm_P0.5mm_EP1.45x1.45mm
U2: USBLC6-2SC6; SOT-23-6
U10: TPS62826DMQ 3.3V; TI_DMQ0006A_VSON-HR-6_1.5x1.5mm
U11: TPS6282618DMQ 1.8V; TI_DMQ0006A_VSON-HR-6_1.5x1.5mm
U20: TPS259531DSGR; DFN-8-1EP_2x2mm_P0.5mm_EP0.9x1.6mm
U100: STM32H573ZIT6; LQFP-144_20x20mm_P0.5mm
U300: CP2102N-A02-GQFN24 DNP; QFN-24-1EP_4x4mm_P0.5mm_EP2.6x2.6mm
U401: ESD204DQA TOF1 SPI; USON-10_2.5x1.0mm_P0.5mm
U402: ESD204DQA TOF1 AUX; USON-10_2.5x1.0mm_P0.5mm
U403: ESD204DQA TOF1 DET; USON-10_2.5x1.0mm_P0.5mm
U404: ESD204DQA TOF2 SPI; USON-10_2.5x1.0mm_P0.5mm
U405: ESD204DQA TOF2 AUX; USON-10_2.5x1.0mm_P0.5mm
U406: ESD204DQA TOF2 DET; USON-10_2.5x1.0mm_P0.5mm
U407: ESD204DQA TOF3 SPI; USON-10_2.5x1.0mm_P0.5mm
U408: ESD204DQA TOF3 AUX; USON-10_2.5x1.0mm_P0.5mm
U409: ESD204DQA TOF3 DET; USON-10_2.5x1.0mm_P0.5mm
U410: ESD204DQA TOF4 SPI; USON-10_2.5x1.0mm_P0.5mm
U411: ESD204DQA TOF4 AUX; USON-10_2.5x1.0mm_P0.5mm
U412: ESD204DQA TOF4 DET; USON-10_2.5x1.0mm_P0.5mm
U413: ESD204DQA TOF5 SPI; USON-10_2.5x1.0mm_P0.5mm
U414: ESD204DQA TOF5 AUX; USON-10_2.5x1.0mm_P0.5mm
U415: ESD204DQA TOF5 DET; USON-10_2.5x1.0mm_P0.5mm

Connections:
BOOT0: R301.1, SW101.1, U100.138
CC1_CONN: C1.1, J1.A5, U1.7
CC2_CONN: C2.1, J1.B5, U1.9
CP2102_DM: R305.2, U300.4
CP2102_DP: R304.2, U300.3
CP2102_RST_N: R308.2, U300.9
CP2102_VBUS_SENSE: R306.2, R307.1, U300.8
EFUSE_DVDT: C6.1, U20.1
EFUSE_FLT_N: R5.2, U20.6, U100.125
EFUSE_ILM: R6.1, U20.7
FB_3V3: C13.2, R10.2, R11.1, U10.3
GND: C1.2, C2.2, C3.2, C4.2, C5.2, C6.2, C10.2, C11.2, C12.2, C20.2, C21.2, C22.2, C201.2, C202.2, C203.2, C204.2, C205.2, C211.2, C212.2, C213.2, C214.2, C215.2, C260.2, C300.2, C301.2, C302.2, C303.2, C304.2, C310.2, C311.2, C312.2, C313.2, C314.2, C315.2, C316.2, C317.2, C318.2, C319.2, C320.2, C321.2, C322.2, C323.2, C330.2, C340.2, C341.2, C342.2, D1.2, J1.A1, J1.A12, J1.B1, J1.B12, J1.SH, J300.3, R2.2, R4.1, R4.2, R6.2, R11.2, R201.2, R202.2, R203.2, R204.2, R205.2, R301.2, R307.2, R312.2, SW100.2, U1.2, U1.13, U2.2, U10.4, U11.4, U20.8, U20.9, U100.16, U100.31, U100.38, U100.51, U100.61, U100.71, U100.83, U100.94, U100.107, U100.120, U100.130, U100.143, U300.2, U300.25, U401.3, U401.8, U402.3, U402.8, U403.3, U403.8, U404.3, U404.8, U405.3, U405.8, U406.3, U406.8, U407.3, U407.8, U408.3, U408.8, U409.3, U409.8, U410.3, U410.8, U411.3, U411.8, U412.3, U412.8, U413.3, U413.8, U414.3, U414.8, U415.3, U415.8
I3C1_SCL_SHARED: R260.2, U100.136, U402.1, U405.1, U408.1, U411.1, U414.1
I3C1_SDA_SHARED: R261.2, U100.137, U402.2, U405.2, U408.2, U411.2, U414.2
MCU_STATUS_LED_A: D100.2, R310.2
MCU_STATUS_LED_N: D100.1, U100.124
MCU_UART_RX: U100.78, U300.21
MCU_UART_TX: U100.77, U300.20
NRST_N: C300.1, J300.5, R300.2, SW100.1, U100.25
P1V8_TOF: C21.1, C22.1, C211.1, C212.1, C213.1, C214.1, C215.1, L11.2, U11.3
P3V3: C11.1, C12.1, C13.1, C201.1, C202.1, C203.1, C204.1, C205.1, C310.1, C311.1, C312.1, C313.1, C314.1, C315.1, C316.1, C317.1, C318.1, C319.1, C320.1, C321.1, C322.1, C323.1, C330.1, C340.1, C341.1, J300.1, L10.2, R3.1, R5.1, R10.1, R12.1, R20.1, R262.1, R271.1, R272.1, R273.1, R274.1, R275.1, R300.1, R308.1, R309.1, R310.1, SW101.2, U1.12, U100.6, U100.17, U100.30, U100.39, U100.52, U100.62, U100.72, U100.84, U100.95, U100.106, U100.108, U100.121, U100.131, U100.144, U300.5, U300.6, U300.7
PGOOD_1V8: R20.2, U11.2
PGOOD_3V3: R12.2, U10.2
SPI1_MISO: U100.42, U401.4
SPI1_MOSI: R242.2, U401.2
SPI1_MOSI_MCU: R242.1, U100.43
SPI1_SCK: R241.2, U401.1
SPI1_SCK_MCU: R241.1, U100.41
SPI2_MISO: U100.28, U404.4
SPI2_MOSI: R244.2, U404.2
SPI2_MOSI_MCU: R244.1, U100.29
SPI2_SCK: R243.2, U404.1
SPI2_SCK_MCU: R243.1, U100.69
SPI3_MISO: U100.112, U407.4
SPI3_MOSI: R246.2, U407.2
SPI3_MOSI_MCU: R246.1, U100.113
SPI3_SCK: R245.2, U407.1
SPI3_SCK_MCU: R245.1, U100.111
SPI4_MISO: U100.66, U410.4
SPI4_MOSI: R248.2, U410.2
SPI4_MOSI_MCU: R248.1, U100.67
SPI4_SCK: R247.2, U410.1
SPI4_SCK_MCU: R247.1, U100.65
SPI5_MISO: U100.20, U413.4
SPI5_MOSI: R250.2, U413.2
SPI5_MOSI_MCU: R250.1, U100.21
SPI5_SCK: R249.2, U413.1
SPI5_SCK_MCU: R249.1, U100.19
STM_USB_DM: R303.2, U100.103
STM_USB_DP: R302.2, U100.104
SWCLK: J300.4, U100.109
SWDIO: J300.2, U100.105
SWO: J300.6, U100.133
SW_1V8: L11.1, U11.5
SW_3V3: L10.1, U10.5
TCPP_DB_N: U1.10, U100.101
TCPP_FLT_N: R3.2, U1.11, U100.98
TOF1_CS_N: R231.2, U100.40, U401.5
TOF1_DET: R221.2, U100.26, U403.1
TOF1_EN: R201.1, U100.79, U402.4
TOF1_INT: R211.2, U100.80, U402.5
TOF1_LED_A: D201.2, R271.2
TOF1_LED_N: D201.1, U100.89
TOF2_CS_N: R232.2, U100.37, U404.5
TOF2_DET: R222.2, U100.27, U406.1
TOF2_EN: R202.1, U100.81, U405.4
TOF2_INT: R212.2, U100.82, U405.5
TOF2_LED_A: D202.2, R272.2
TOF2_LED_N: D202.1, U100.90
TOF3_CS_N: R233.2, U100.116, U407.5
TOF3_DET: R223.2, U100.44, U409.1
TOF3_EN: R203.1, U100.58, U408.4
TOF3_INT: R213.2, U100.59, U408.5
TOF3_LED_A: D203.2, R273.2
TOF3_LED_N: D203.1, U100.91
TOF4_CS_N: R234.2, U100.64, U410.5
TOF4_DET: R224.2, U100.45, U412.1
TOF4_EN: R204.1, U100.60, U411.4
TOF4_INT: R214.2, U100.63, U411.5
TOF4_LED_A: D204.2, R274.2
TOF4_LED_N: D204.1, U100.92
TOF5_CS_N: R235.2, U100.18, U413.5
TOF5_DET: R225.2, U100.34, U415.1
TOF5_EN: R205.1, U100.87, U414.4
TOF5_INT: R215.2, U100.88, U414.5
TOF5_LED_A: D205.2, R275.2
TOF5_LED_N: D205.1, U100.93
TOF_VIO: C260.1, R211.1, R212.1, R213.1, R214.1, R215.1, R221.1, R222.1, R223.1, R224.1, R225.1, R231.1, R232.1, R233.1, R234.1, R235.1, R260.1, R261.1, R262.2
UCPD_CC1: U1.3, U100.74
UCPD_CC2: U1.1, U100.75
USB_DM_CONN: J1.A7, J1.B7, U2.3
USB_DM_PROT: R303.1, R305.1, U2.4
USB_DP_CONN: J1.A6, J1.B6, U2.1
USB_DP_PROT: R302.1, R304.1, U2.6
VBUS_CTRL: R1.2, R2.1, U1.6
VBUS_FUSED: C5.1, C10.1, C20.1, R311.1, U10.1, U10.6, U11.1, U11.6, U20.5
VBUS_GATE: Q1.5, U1.5
VBUS_IN: D1.1, J1.A4, J1.A9, J1.B4, J1.B9, Q1.1, Q1.2, Q1.3, Q1.4, R1.1, U1.8, U2.5
VBUS_SENSE_ADC: C342.1, R311.2, R312.1, U100.35
VBUS_SYS: C3.1, C4.1, Q1.6, Q1.7, Q1.8, R306.1, U1.4, U20.2, U20.3, U20.4
VCAP1: C301.1, U100.70
VCAP2: C302.1, U100.142
VDDA_3V3: C303.1, C304.1, R309.2, U100.32, U100.33

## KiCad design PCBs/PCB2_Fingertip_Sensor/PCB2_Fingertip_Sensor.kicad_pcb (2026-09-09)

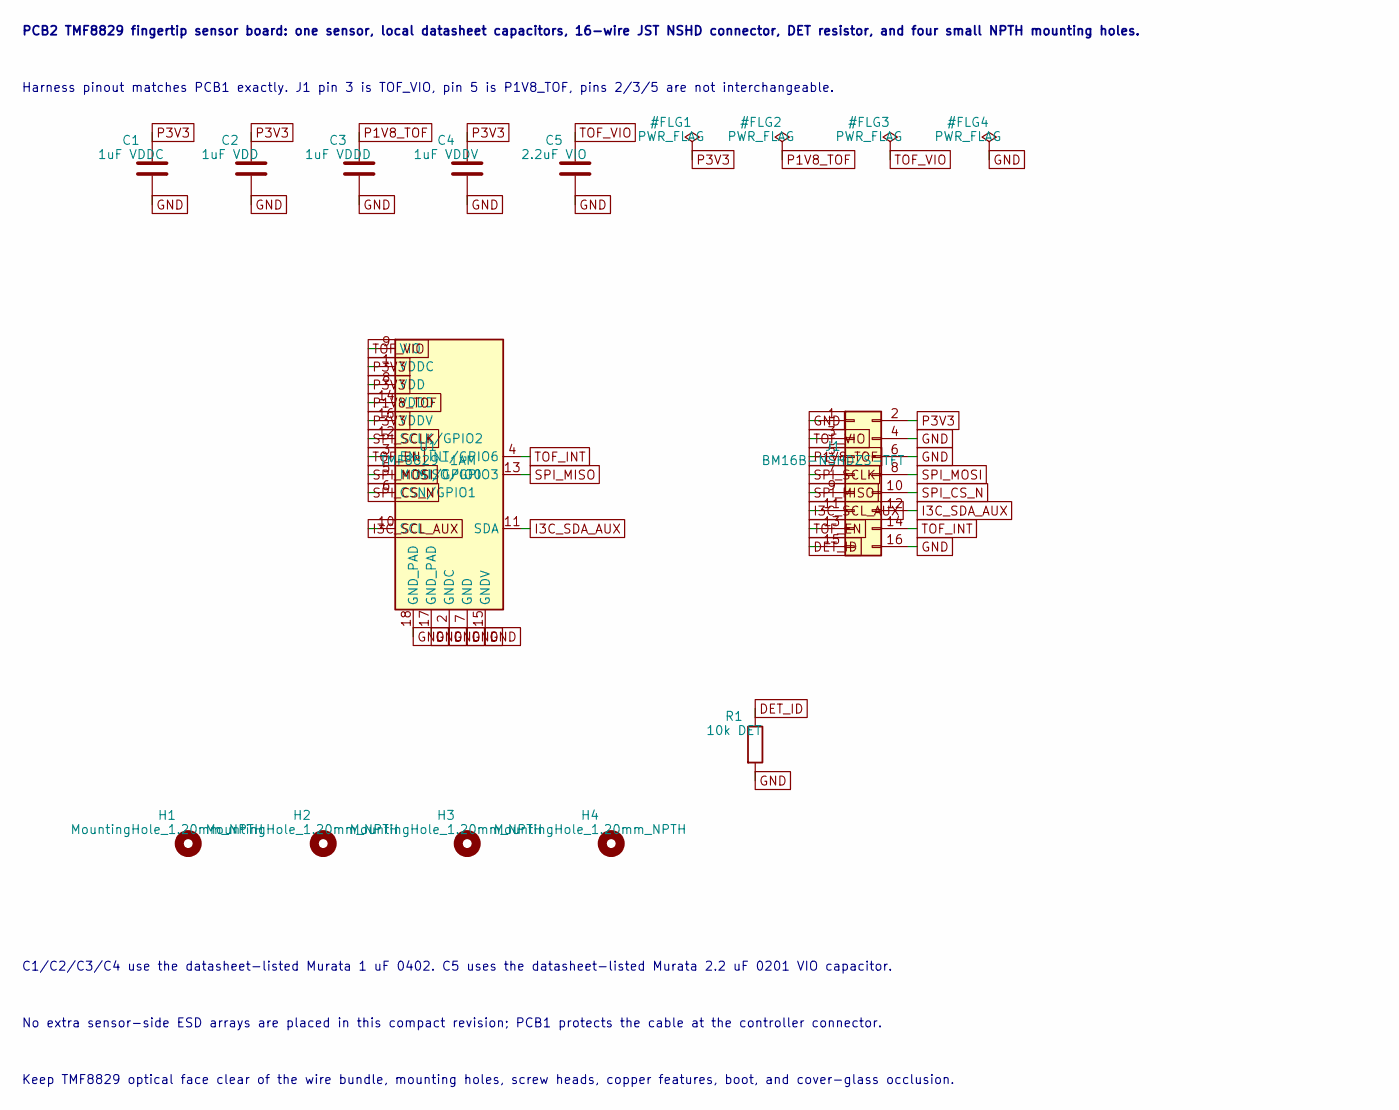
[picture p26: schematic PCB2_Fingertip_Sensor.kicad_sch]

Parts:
C1: 1uF VDDC; C_0402_1005Metric; MPN GRM155R70J105KA12
C2: 1uF VDD; C_0402_1005Metric; MPN GRM155R70J105KA12
C3: 1uF VDDD; C_0402_1005Metric; MPN GRM155R70J105KA12
C4: 1uF VDDV; C_0402_1005Metric; MPN GRM155R70J105KA12
C5: 2.2uF VIO; C_0201_0603Metric; MPN GRM033R60J225ME47
H1, H2, H3, H4: MountingHole_1.20mm_NPTH
J1: BM16B-NSHDZS-TFT; JST_BM16B-NSHDZS-TFT_2x08_P1.00mm_Vertical; MPN BM16B-NSHDZS-TFT; DigiKey_PN 455-BM16B-NSHDZS-TFTCT-ND
R1: 10k DET; R_0402_1005Metric; MPN RC0402FR-0710KL
U1: TMF8829-1AM; ams_OSRAM_TMF8829_OLGA-18_5.7x2.9mm; MPN TMF8829-1AM

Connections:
DET_ID: J1.15, R1.1
GND: C1.2, C2.2, C3.2, C4.2, C5.2, J1.1, J1.4, J1.6, J1.16, R1.2, U1.2 (GNDC), U1.7 (GND), U1.15 (GNDV), U1.17 (GND_PAD), U1.18 (GND_PAD)
I3C_SCL_AUX: J1.11, U1.10 (SCL)
I3C_SDA_AUX: J1.12, U1.11 (SDA)
P1V8_TOF: C3.1, J1.5, U1.14 (VDDD)
P3V3: C1.1, C2.1, C4.1, J1.2, U1.1 (VDDC), U1.8 (VDD), U1.16 (VDDV)
SPI_CS_N: J1.10, U1.6 (CSN/GPIO1)
SPI_MISO: J1.9, U1.13 (MISO/GPIO3)
SPI_MOSI: J1.8, U1.5 (MOSI/GPIO0)
SPI_SCLK: J1.7, U1.12 (SCLK/GPIO2)
TOF_EN: J1.13, U1.3 (EN)
TOF_INT: J1.14, U1.4 (INT/GPIO6)
TOF_VIO: C5.1, J1.3, U1.9 (VIO)

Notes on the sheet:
PCB2 TMF8829 fingertip sensor board: one sensor, local datasheet capacitors, 16-wire JST NSHD connector, DET resistor, and four small NPTH mounting holes.
Harness pinout matches PCB1 exactly. J1 pin 3 is TOF_VIO, pin 5 is P1V8_TOF, pins 2/3/5 are not interchangeable.
C1/C2/C3/C4 use the datasheet-listed Murata 1 uF 0402. C5 uses the datasheet-listed Murata 2.2 uF 0201 VIO capacitor.
No extra sensor-side ESD arrays are placed in this compact revision; PCB1 protects the cable at the controller connector.
Keep TMF8829 optical face clear of the wire bundle, mounting holes, screw heads, copper features, boot, and cover-glass occlusion.

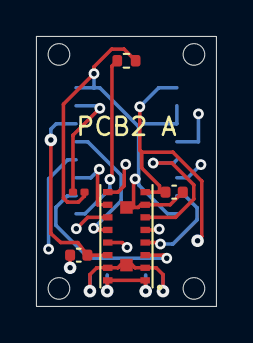
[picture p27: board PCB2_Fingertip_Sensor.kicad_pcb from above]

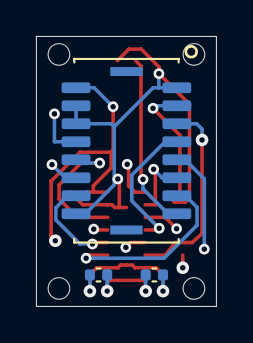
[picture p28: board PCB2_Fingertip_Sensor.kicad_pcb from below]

Board: 4 copper layers, 10.0 x 15.0 mm, 12 parts (3 on the bottom side), 13 nets.

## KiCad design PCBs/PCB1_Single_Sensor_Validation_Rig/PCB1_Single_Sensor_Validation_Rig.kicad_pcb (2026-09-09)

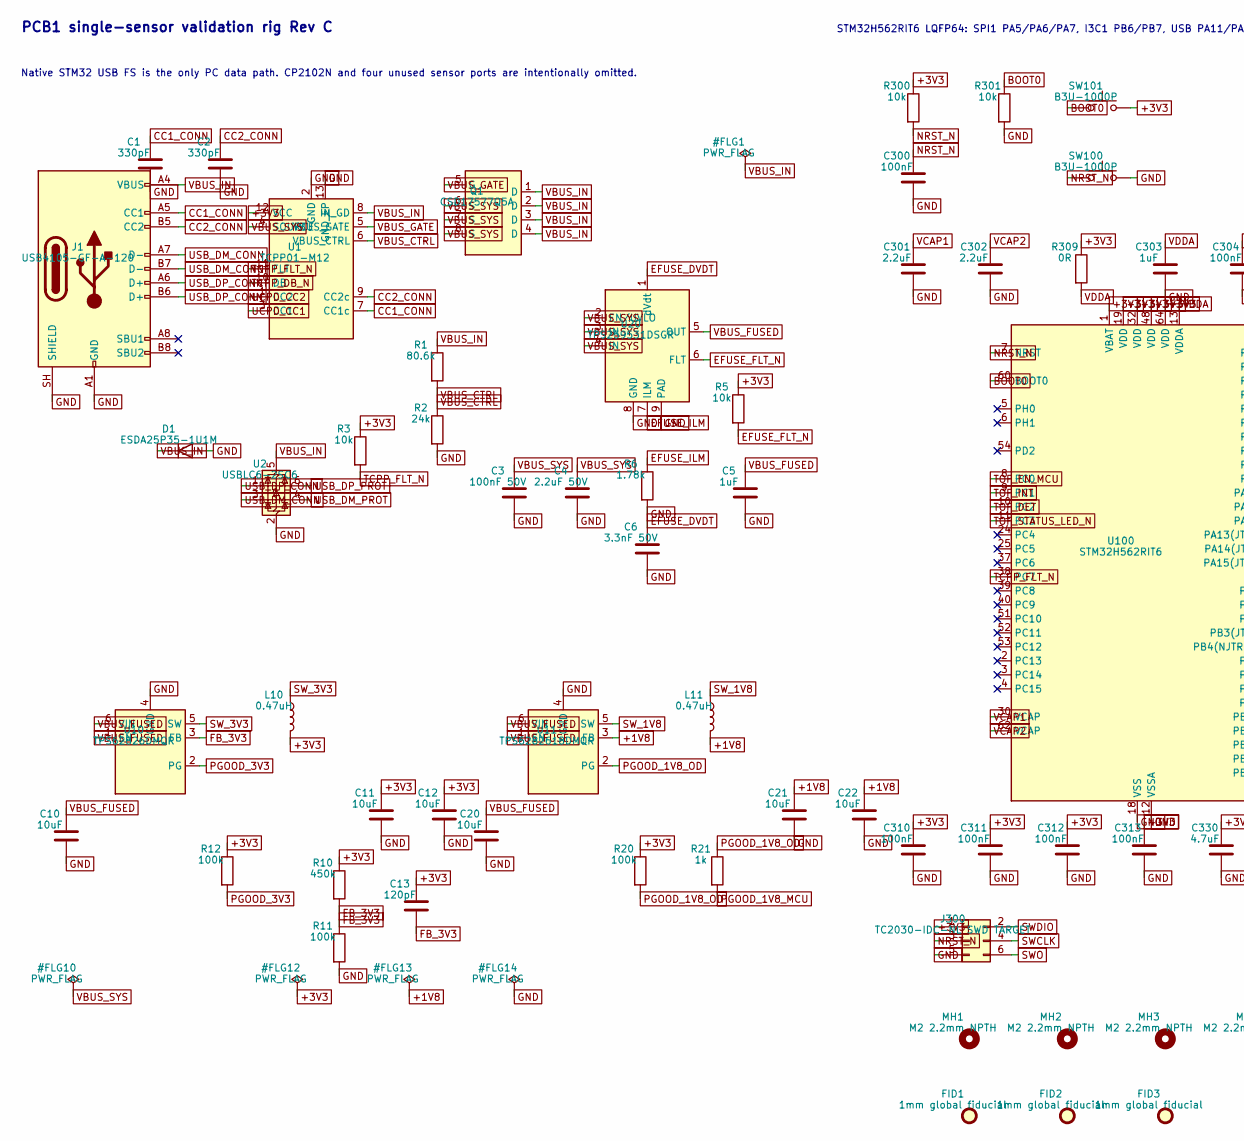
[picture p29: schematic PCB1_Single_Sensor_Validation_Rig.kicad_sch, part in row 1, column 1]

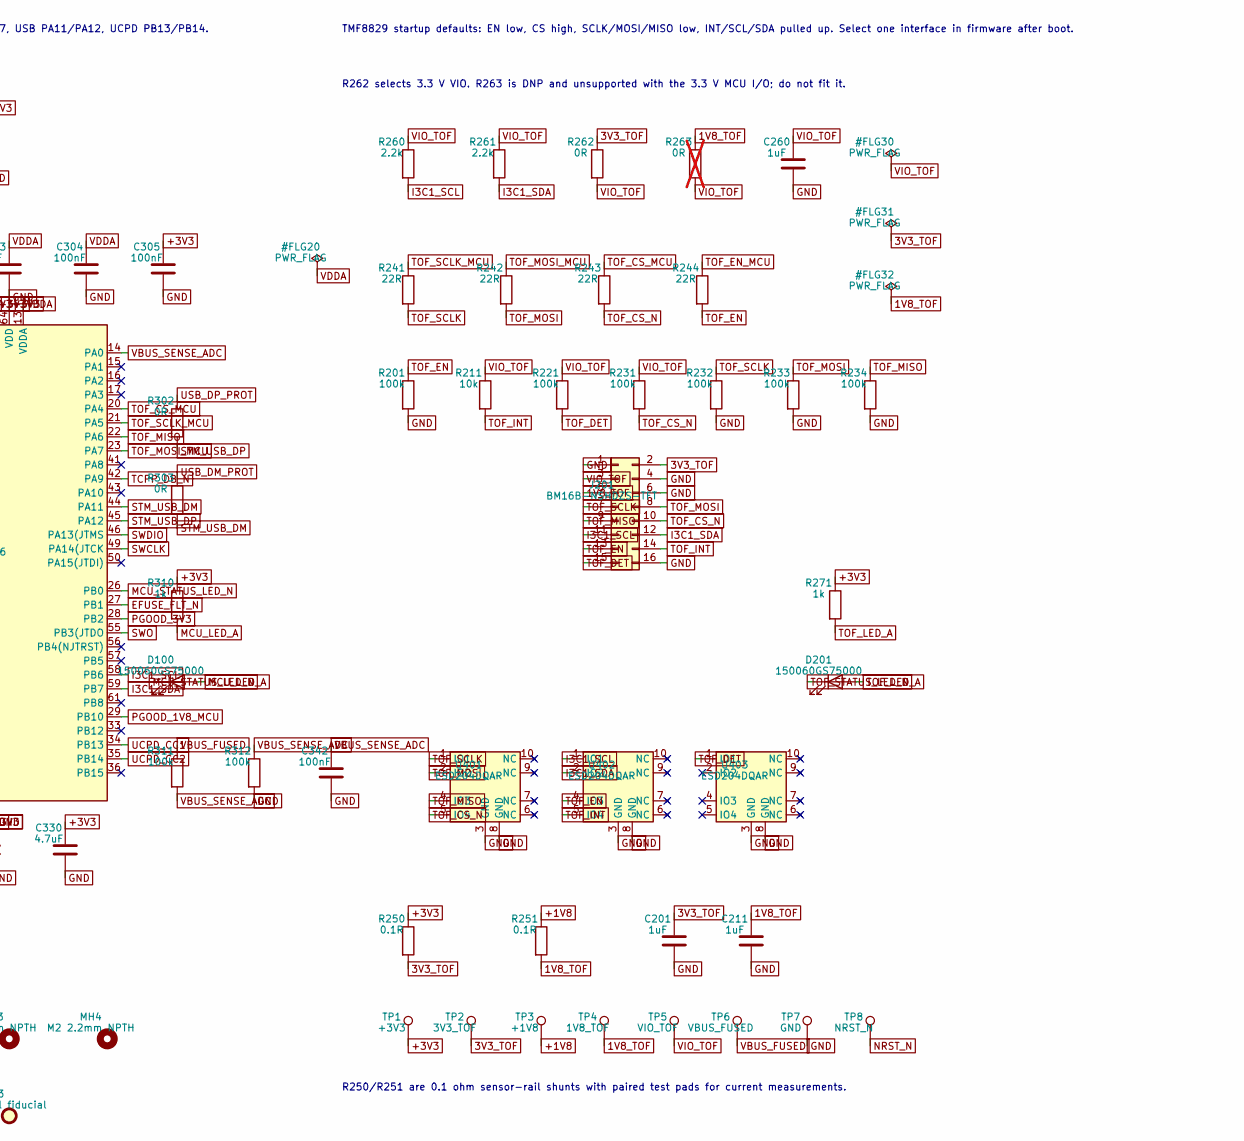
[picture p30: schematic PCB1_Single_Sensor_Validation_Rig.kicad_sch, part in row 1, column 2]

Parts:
C1, C2: 330pF; C_0402_1005Metric; MPN GRM1555C1H331GA01D
C3: 100nF 50V; C_0402_1005Metric; MPN GRM155R71H104KE14D
C4: 2.2uF 50V; C_0603_1608Metric; MPN GRM188R61H225KE11D
C5, C201, C211, C260, C303: 1uF; C_0402_1005Metric; MPN GRM155R61A105KE15D
C6: 3.3nF 50V; C_0402_1005Metric; MPN GRM155R71H332KA01D
C10, C11, C12, C20, C21, C22: 10uF; C_0603_1608Metric; MPN GRM188Z71A106MA73D
C13: 120pF; C_0402_1005Metric; MPN GRM1555C1H121JA01D
C300, C304, C305, C310, C311, C312, C313, C342: 100nF; C_0402_1005Metric; MPN GRM155R71C104KA88D
C301, C302: 2.2uF; C_0603_1608Metric; MPN GRM188R61H225KE11D
C330: 4.7uF; C_0603_1608Metric; MPN GRM188R60J475KE19D
D1: ESDA25P35-1U1M; ST_QFN-2L_1.6x1.0mm; MPN ESDA25P35-1U1M
D100, D201: 150060GS75000; LED_0603_1608Metric; MPN 150060GS75000
FID1, FID2, FID3: 1mm global fiducial; Fiducial_1mm_Mask2mm
J1: USB4105-GF-A-120; USB_C_Receptacle_GCT_USB4105-xx-A_16P_TopMnt_Horizontal; MPN USB4105-GF-A-120
J201: BM16B-NSHDZS-TFT; JST_BM16B-NSHDZS-TFT_2x08_P1.00mm_Vertical; MPN BM16B-NSHDZS-TFT
J300: TC2030-IDC-NL SWD TARGET; Tag-Connect_TC2030-IDC-NL_2x03_P1.27mm_Vertical; MPN TC2030-IDC-NL
L10, L11: 0.47uH; TDK_TFM201610ALM-R47MTAA_2.0x1.6mm; MPN TFM201610ALM-R47MTAA
MH1, MH2, MH3, MH4: M2 2.2mm NPTH; MountingHole_2.2mm_M2
Q1: CSD17577Q5A; TI_CSD17577Q5A_DQJ_VSONP-8_4.9x6.0mm; MPN CSD17577Q5A
R1: 80.6k; R_0402_1005Metric; MPN RC0402FR-0780K6L
R2: 24k; R_0402_1005Metric; MPN RC0402FR-0724KL
R3, R5, R211, R300, R301: 10k; R_0402_1005Metric; MPN RC0402FR-0710KL
R6: 1.78k; R_0402_1005Metric; MPN RC0402FR-071K78L
R10: 450k; R_0402_1005Metric; MPN FRC0402F4503TS
R11, R12, R20, R201, R221, R231, R232, R233, R234, R311, R312: 100k; R_0402_1005Metric; MPN RC0402FR-07100KL
R21, R271, R310: 1k; R_0402_1005Metric; MPN RC0402FR-071KL
R241, R242, R243, R244: 22R; R_0402_1005Metric; MPN RC0402FR-0722RL
R250, R251: 0.1R; R_0402_1005Metric; MPN RL0402FR-070R1L
R260, R261: 2.2k; R_0402_1005Metric; MPN RC0402FR-072K2L
R262, R302, R303, R309: 0R; R_0402_1005Metric; MPN RC0402JR-070RL
R263: 0R; R_0402_1005Metric; MPN RC0402JR-070RL; not fitted
SW100, SW101: B3U-1000P; SW_SPST_B3U-1000P; MPN B3U-1000P
TP1: +3V3; TestPoint_Pad_D1.0mm
TP2: 3V3_TOF; TestPoint_Pad_D1.0mm
TP3: +1V8; TestPoint_Pad_D1.0mm
TP4: 1V8_TOF; TestPoint_Pad_D1.0mm
TP5: VIO_TOF; TestPoint_Pad_D1.0mm
TP6: VBUS_FUSED; TestPoint_Pad_D1.0mm
TP7: GND; TestPoint_Pad_D1.0mm
TP8: NRST_N; TestPoint_Pad_D1.0mm
U1: TCPP01-M12; QFN-12-1EP_3x3mm_P0.5mm_EP1.45x1.45mm; MPN TCPP01-M12
U2: USBLC6-2SC6; SOT-23-6; MPN USBLC6-2SC6
U10: TPS62826DMQR; TI_DMQ0006A_VSON-HR-6_1.5x1.5mm; MPN TPS62826DMQR
U11: TPS6282618DMQR; TI_DMQ0006A_VSON-HR-6_1.5x1.5mm; MPN TPS6282618DMQR
U20: TPS259531DSGR; DFN-8-1EP_2x2mm_P0.5mm_EP0.9x1.6mm; MPN TPS259531DSGR
U100: STM32H562RIT6; LQFP-64_10x10mm_P0.5mm; MPN STM32H562RIT6
U401, U402, U403: ESD204DQAR; USON-10_2.5x1.0mm_P0.5mm; MPN ESD204DQAR

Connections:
1V8_TOF: C211.1, J201.5, R251.2, R263.1, TP4.1
3V3_TOF: C201.1, J201.2, R250.2, R262.1, TP2.1
+1V8: C21.1, C22.1, L11.2, R251.1, TP3.1, U11.3 (FB)
+3V3: C11.1, C12.1, C13.1, C305.1, C310.1, C311.1, C312.1, C313.1, C330.1, J300.1, L10.2, R3.1, R5.1, R10.1, R12.1, R20.1, R250.1, R271.1, R300.1, R309.1, R310.1, SW101.2, TP1.1, U1.12 (VCC), U100.1 (VBAT), U100.19 (VDD), U100.32 (VDD), U100.48 (VDD), U100.64 (VDD)
BOOT0: R301.1, SW101.1, U100.60 (BOOT0)
CC1_CONN: C1.1, J1.A5 (CC1), U1.7 (CC1c)
CC2_CONN: C2.1, J1.B5 (CC2), U1.9 (CC2c)
EFUSE_DVDT: C6.1, U20.1 (dVdt)
EFUSE_FLT_N: R5.2, U20.6 (FLT), U100.27 (PB1)
EFUSE_ILM: R6.1, U20.7 (ILM)
FB_3V3: C13.2, R10.2, R11.1, U10.3 (FB)
GND: C1.2, C2.2, C3.2, C4.2, C5.2, C6.2, C10.2, C11.2, C12.2, C20.2, C21.2, C22.2, C201.2, C211.2, C260.2, C300.2, C301.2, C302.2, C303.2, C304.2, C305.2, C310.2, C311.2, C312.2, C313.2, C330.2, C342.2, D1.2 (A), J1.A1 (GND), J1.A12 (GND), J1.B1 (GND), J1.B12 (GND), J1.SH (SHIELD), J201.1, J201.4, J201.6, J201.16, J300.5, R2.2, R6.2, R11.2, R201.2, R232.2, R233.2, R234.2, R301.2, R312.2, SW100.2, TP7.1, U1.2 (GND), U1.13 (GND_EP), U2.2 (GND), U10.4 (GND), U11.4 (GND), U20.8 (GND), U20.9 (PAD), U100.12 (VSSA), U100.18 (VSS), U100.31 (VSS), U100.47 (VSS), U100.63 (VSS), U401.3 (GND), U401.8 (GND), U402.3 (GND), U402.8 (GND), U403.3 (GND), U403.8 (GND)
I3C1_SCL: J201.11, R260.2, U100.58 (PB6), U402.1 (IO1)
I3C1_SDA: J201.12, R261.2, U100.59 (PB7), U402.2 (IO2)
MCU_LED_A: D100.2 (A), R310.2
MCU_STATUS_LED_N: D100.1 (K), U100.26 (PB0)
NRST_N: C300.1, J300.3, R300.2, SW100.1, TP8.1, U100.7 (NRST)
PGOOD_1V8_MCU: R21.2, U100.29 (PB10)
PGOOD_1V8_OD: R20.2, R21.1, U11.2 (PG)
PGOOD_3V3: R12.2, U10.2 (PG), U100.28 (PB2)
STM_USB_DM: R303.2, U100.44 (PA11)
STM_USB_DP: R302.2, U100.45 (PA12)
SWCLK: J300.4, U100.49 (PA14(JTCK)
SWDIO: J300.2, U100.46 (PA13(JTMS)
SWO: J300.6, U100.55 (PB3(JTDO)
SW_1V8: L11.1, U11.5 (SW)
SW_3V3: L10.1, U10.5 (SW)
TCPP_DB_N: U1.10 (DB), U100.42 (PA9)
TCPP_FLT_N: R3.2, U1.11 (FLT), U100.38 (PC7)
TOF_CS_MCU: R243.1, U100.20 (PA4)
TOF_CS_N: J201.10, R231.2, R243.2, U401.5 (IO4)
TOF_DET: J201.15, R221.2, U100.10 (PC2), U403.1 (IO1)
TOF_EN: J201.13, R201.1, R244.2, U402.4 (IO3)
TOF_EN_MCU: R244.1, U100.8 (PC0)
TOF_INT: J201.14, R211.2, U100.9 (PC1), U402.5 (IO4)
TOF_LED_A: D201.2 (A), R271.2
TOF_MISO: J201.9, R234.1, U100.22 (PA6), U401.4 (IO3)
TOF_MOSI: J201.8, R233.1, R242.2, U401.2 (IO2)
TOF_MOSI_MCU: R242.1, U100.23 (PA7)
TOF_SCLK: J201.7, R232.1, R241.2, U401.1 (IO1)
TOF_SCLK_MCU: R241.1, U100.21 (PA5)
TOF_STATUS_LED_N: D201.1 (K), U100.11 (PC3)
UCPD_CC1: U1.3 (CC1), U100.34 (PB13)
UCPD_CC2: U1.1 (CC2), U100.35 (PB14)
USB_DM_CONN: J1.A7 (D-), J1.B7 (D-), U2.3 (I/O2)
USB_DM_PROT: R303.1, U2.4 (I/O2)
USB_DP_CONN: J1.A6 (D+), J1.B6 (D+), U2.1 (I/O1)
USB_DP_PROT: R302.1, U2.6 (I/O1)
VBUS_CTRL: R1.2, R2.1, U1.6 (VBUS_CTRL)
VBUS_FUSED: C5.1, C10.1, C20.1, R311.1, TP6.1, U10.1 (EN), U10.6 (VIN), U11.1 (EN), U11.6 (VIN), U20.5 (OUT)
VBUS_GATE: Q1.5 (G), U1.5 (VBUS_GATE)
VBUS_IN: D1.1 (K), J1.A4 (VBUS), J1.A9 (VBUS), J1.B4 (VBUS), J1.B9 (VBUS), Q1.1 (D), Q1.2 (D), Q1.3 (D), Q1.4 (D), R1.1, U1.8 (IN_GD), U2.5 (VBUS)
VBUS_SENSE_ADC: C342.1, R311.2, R312.1, U100.14 (PA0)
VBUS_SYS: C3.1, C4.1, Q1.6 (S), Q1.7 (S), Q1.8 (S), U1.4 (SOURCE), U20.2 (EN/UVLO), U20.3 (IN), U20.4 (IN)
VCAP1: C301.1, U100.30 (VCAP)
VCAP2: C302.1, U100.62 (VCAP)
VDDA: C303.1, C304.1, R309.2, U100.13 (VDDA)
VIO_TOF: C260.1, J201.3, R211.1, R221.1, R231.1, R260.1, R261.1, R262.2, R263.2, TP5.1

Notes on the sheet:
PCB1 single-sensor validation rig Rev C
Native STM32 USB FS is the only PC data path. CP2102N and four unused sensor ports are intentionally omitted.
STM32H562RIT6 LQFP64: SPI1 PA5/PA6/PA7, I3C1 PB6/PB7, USB PA11/PA12, UCPD PB13/PB14.
TMF8829 startup defaults: EN low, CS high, SCLK/MOSI/MISO low, INT/SCL/SDA pulled up. Select one interface in firmware after boot.
R262 selects 3.3 V VIO. R263 is DNP and unsupported with the 3.3 V MCU I/O; do not fit it.
R250/R251 are 0.1 ohm sensor-rail shunts with paired test pads for current measurements.

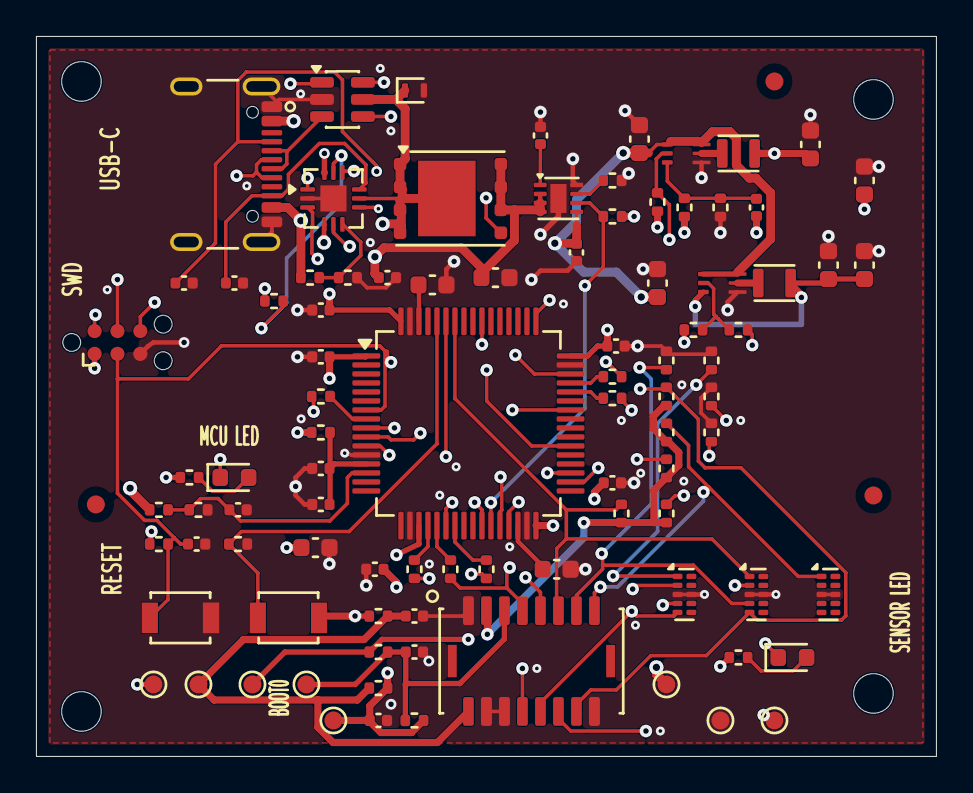
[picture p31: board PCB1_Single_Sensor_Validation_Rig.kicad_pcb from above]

Board: 6 copper layers, 50.0 x 40.0 mm, 99 parts (0 on the bottom side), 58 nets.

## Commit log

2026-06-11 Add TMF8829 PCB documentation vault
    [TMF8829_Rubber_Boot_0mm3.STEP, TMF8829_with_FOI_FOV.STEP]
2026-09-09 Organize PCB projects and corrected tactile sensor CAD
    [JST_BM16B_NSHDZS_TFT_envelope_proxy.step, MCU_Debug.kicad_sch, P3_optical_cassette.step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]
2026-09-09 Show assembly and sensing visuals at the top of the README
